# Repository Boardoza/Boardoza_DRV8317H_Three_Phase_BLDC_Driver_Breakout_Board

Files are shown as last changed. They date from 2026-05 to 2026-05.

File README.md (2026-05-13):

# Boardoza DRV8317H Three-Phase BLDC Motor Driver Breakout Board

The **Boardoza DRV8317H Breakout Board** is a high-performance, integrated **three-phase BLDC motor driver** designed for compact and efficient motor control applications. Based on the **Texas Instruments DRV8317H**, this device integrates three half-bridges with low R<sub>DS(ON)</sub> MOSFETs, programmable current sensing, and advanced protection mechanisms into a single solution.

Supporting supply voltages up to **24V (absolute maximum)** and delivering up to **5A peak output current**, the DRV8317H is ideal for robotics, steward and gimbal systems, drones, industrial automation, pumps, and smart motorized systems. With flexible control options such as **6x PWM mode and 3x PWM mode**, this board allows both simple and advanced motor control implementations.

## [Click here to purchase!](https://www.ozdisan.com/ureticiler/boardoza)

| Front Side | Back Side |
|:---:|:---:|
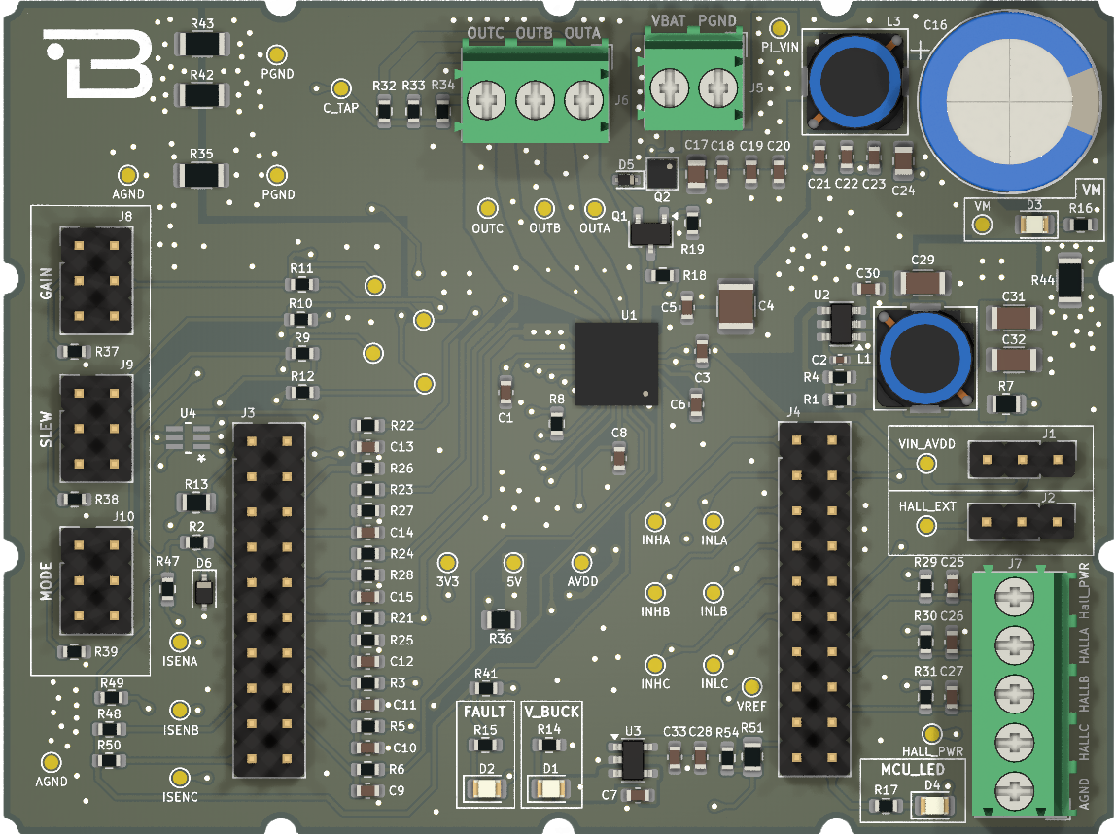
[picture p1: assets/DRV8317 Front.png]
DRV8317H Front
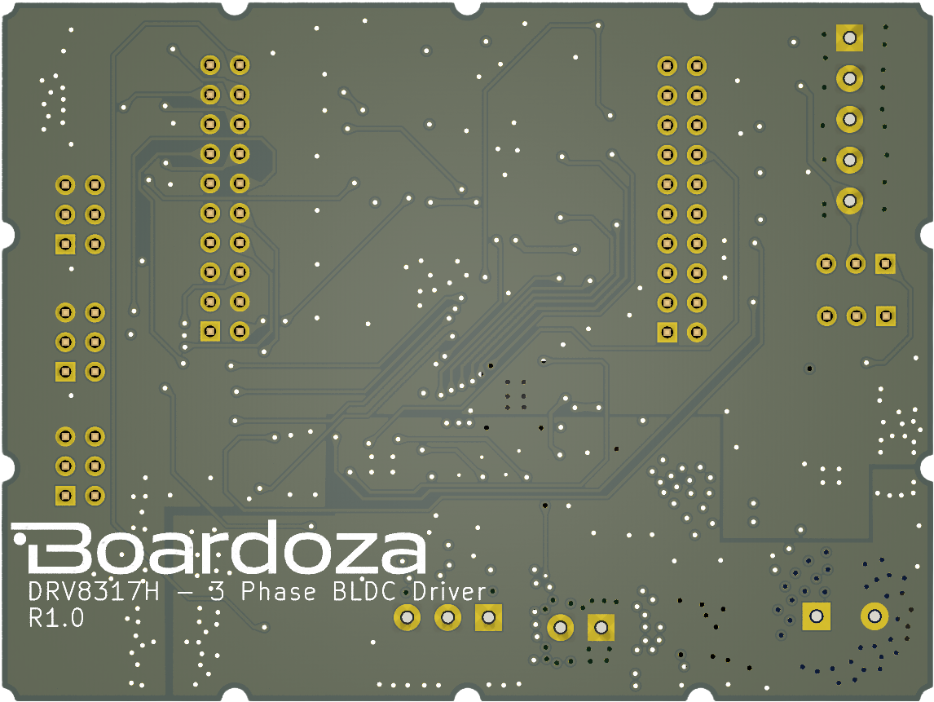
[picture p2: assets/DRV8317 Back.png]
DRV8317H Back
|  |  |

---

## Key Features

- **Integrated Three-Phase Driver:** Drives BLDC and PMSM motors with a compact all-in-one solution.
- **Up to 5A Peak Output Current:** Suitable for medium-power motor applications.
- **Flexible Control Options:** Supports **6x PWM** and **3x PWM**.
- **High PWM Frequency Support:** Operates with PWM frequencies up to **200 kHz**.
- **Integrated Current Sensing:** No external shunt resistor required.
- **Programmable Slew Rate:** Helps reduce EMI and optimize switching performance.
- **Comprehensive Protection Features:** Includes UVLO, OVP, CPUV, OCP, OTW, and OTS protections.
- **Shoot-Through Protection:** Integrated hardware-level safety for reliable operation.

---

## Technical Specifications

**Model:** DRV8317H  
**Manufacturer:** Boardoza  
**Manufacturer IC:** Texas Instruments  
**Driver Type:** Integrated 3-Phase Gate Driver with MOSFETs  
**Functions:** Three-Phase PWM BLDC Motor Driver  
**Input Voltage (VM):** 4.5V – 20V (24V Absolute Maximum)  
**Peak Output Current:** 5A (per phase, peak)  
**Control Interfaces:** 6x PWM / 3x PWM    
**Maximum PWM Frequency:** 200 kHz  
**RDS(ON) (HS + LS):** 130 mΩ (typical at 25°C)  
**Current Sensing:** Integrated (Programmable Gain)  
**Protection Features:**  
- UVLO (Undervoltage Lockout)  
- OVP (Overvoltage Protection)  
- CPUV (Charge Pump Undervoltage)  
- OCP (Overcurrent Protection)  
- OTW (Overtemperature Warning)  
- OTS (Overtemperature Shutdown)  

**Operating Temperature:** -40°C to +125°C  
**Board Dimensions:** 60mm x 80mm  

---

## Board Pinout / User Guide

>Pin functions are multiplexed and may vary depending on selected control mode (6x PWM, 3x PWM).  
For detailed pin descriptions, alternate-function mappings, electrical characteristics, and application examples, please refer to the official Board User Guide:
[DRV8317H User Guide.pdf](./assets/DRV8317H%20User%20Guide.pdf)

---

## Board Dimensions

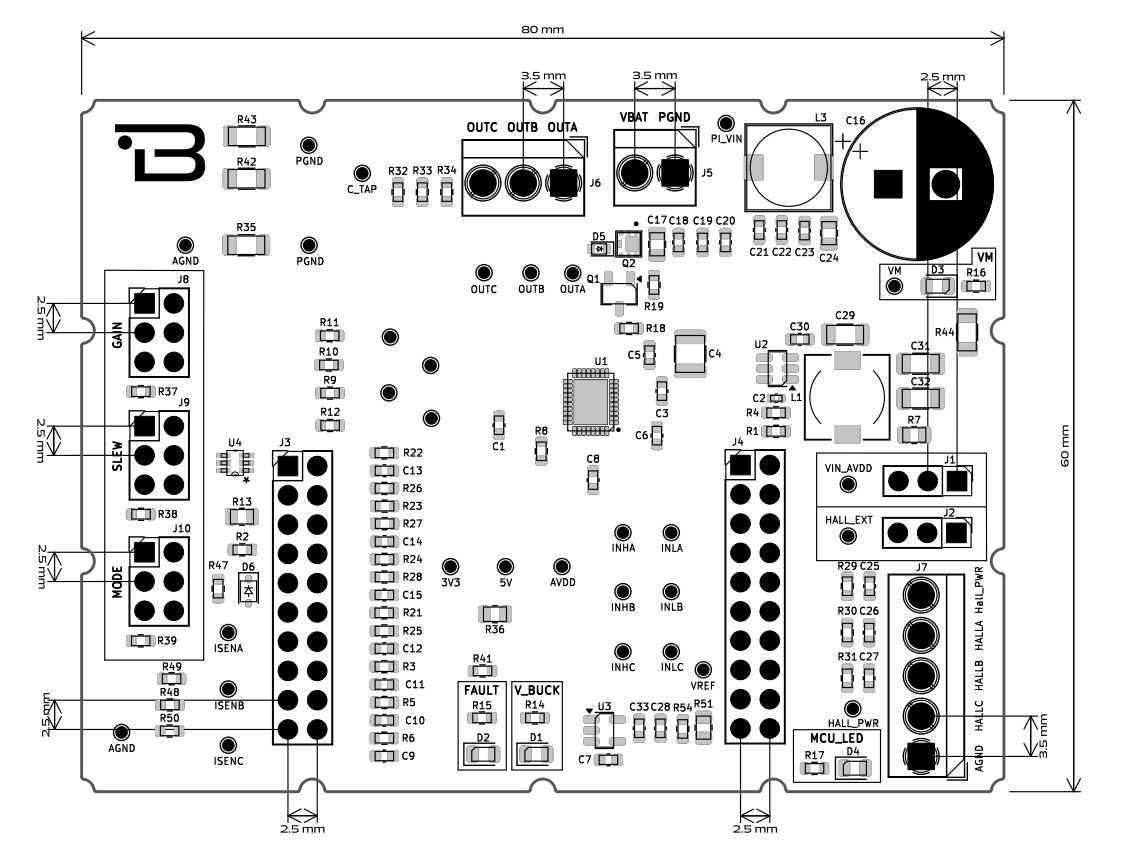
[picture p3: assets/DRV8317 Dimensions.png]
DRV8317H Board Dimensions


---

## Step Files

[Boardoza DRV8317H.step](./assets/DRV8317%20Step.step)

---

## Datasheet

[DRV8317H Datasheet.pdf](./assets/DRV8317%20Datasheet.pdf)

---

## Version History

- v1.0.0 - Initial Release

---

## Support

- If you have any questions or need support, please contact **support@boardoza.com**

---

## **License**

This repository contains both hardware and software components:

### **Hardware Design**

[][cc-by-sa]

All hardware design files are licensed under [Creative Commons Attribution-ShareAlike 4.0 International License][cc-by-sa].

[cc-by-sa]: http://creativecommons.org/licenses/by-sa/4.0/
[cc-by-sa-shield]: https://img.shields.io/badge/License-CC%20BY--SA%204.0-lightgrey.svg

### **Software/Firmware**

[][bsd]

All software and firmware are licensed under [BSD 3-Clause License][bsd].

[bsd]: https://opensource.org/licenses/BSD-3-Clause
[bsd-shield]: https://img.shields.io/badge/License-BSD%203--Clause-blue.svg

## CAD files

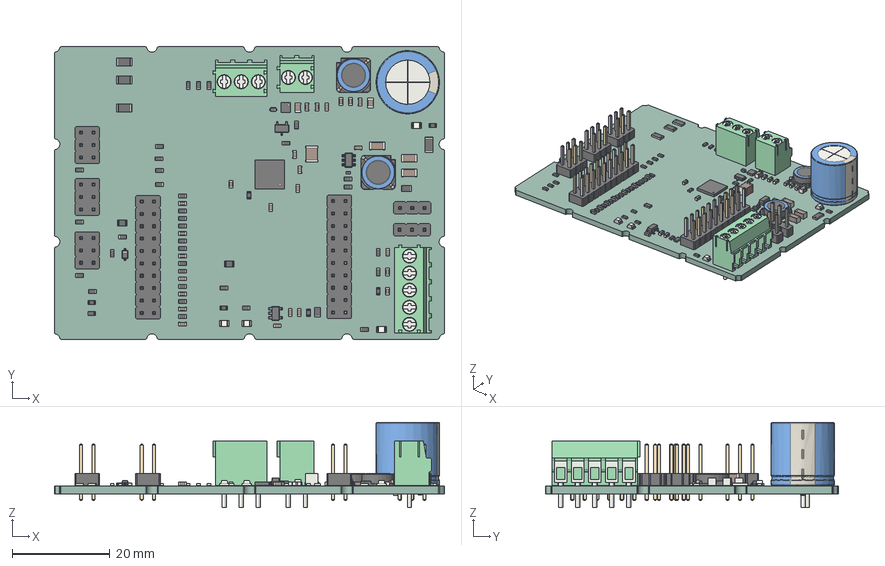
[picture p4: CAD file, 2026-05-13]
assets/DRV8317 Step.step
80.0 x 60.0 x 17.5 mm
R_0603_1608Metric x 40
D_SOD_523
C_0603_1608Metric x 25
C_0805_2012Metric x 2
TSOT_23
D_SOD_323
PinHeader_1x03_P254mm_Vertical x 2
R_0805_2012Metric x 4
SOT_23_5
Sf㱟fd_sp x 2
C_1206_3216Metric x 3
LED_0805_2012Metric x 4
PinHeader_2x10_P254mm_Vertical x 2
PinHeader_2x03_P254mm_Vertical x 3
C_1210_3225Metric
TerminalBlock_Phoenix_PT_15_2_35_H_1x02_P350mm_Horizontal
TerminalBlock_Phoenix_PT_15_3_35_H_1x03_P350mm_Horizontal
TerminalBlock_Phoenix_PT_15_5_35_H_1x05_P350mm_Horizontal
DFN-6-1EP_2x2mm_Pitch0.65mm
R_1206_3216Metric x 4
Texas_RHH0036C_VQFN-36-1EP_6x6mm_P0.5mm_EP4.4x4.4mm
C_0402_1005Metric
CP_Radial_D130mm_P500mm
SOT_23_6
_autosave-B-DRV8317-BRK_PCB

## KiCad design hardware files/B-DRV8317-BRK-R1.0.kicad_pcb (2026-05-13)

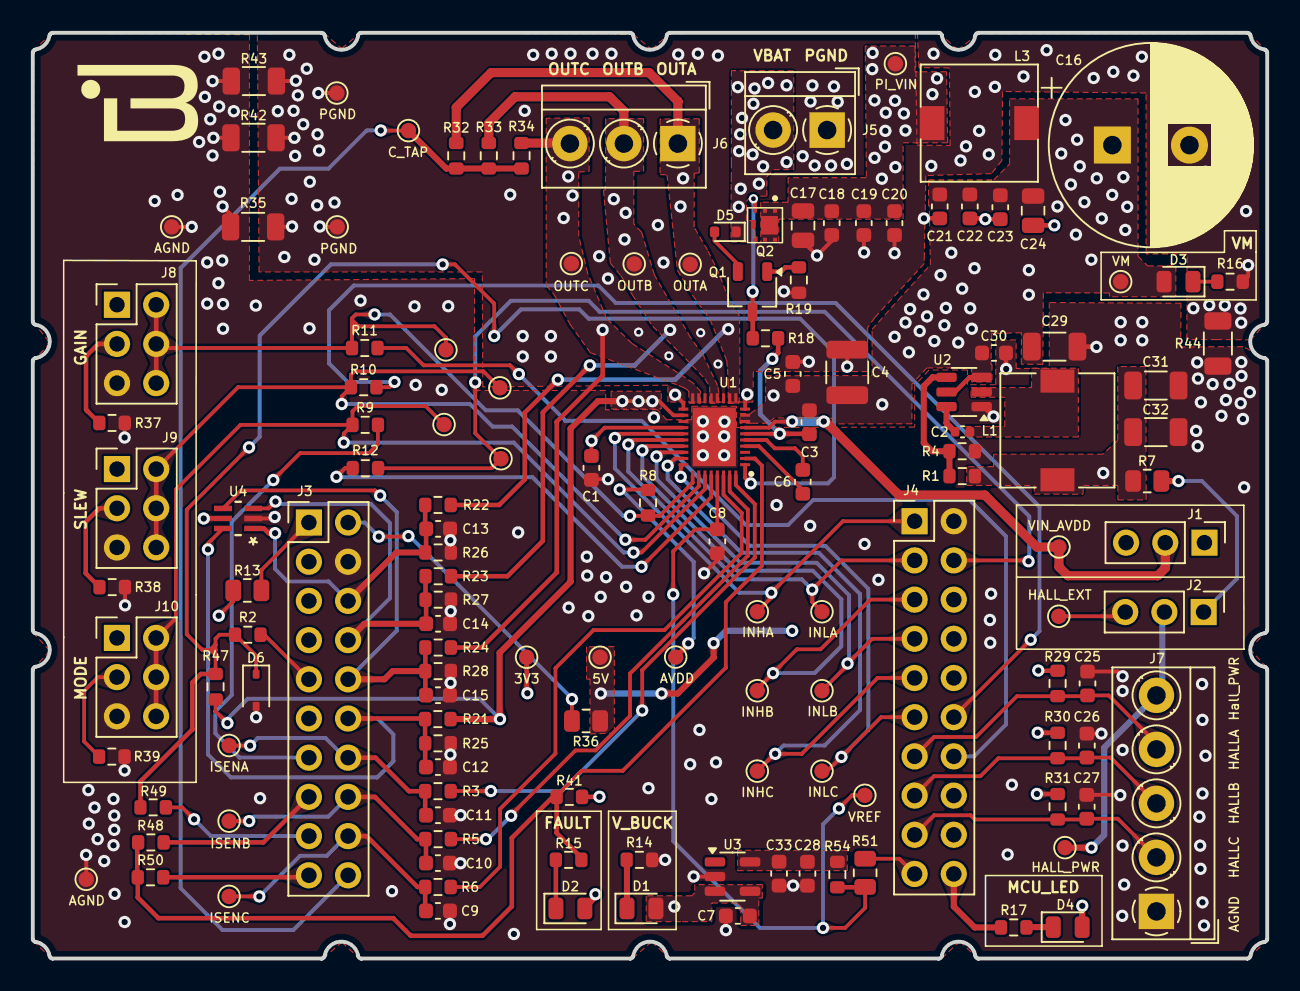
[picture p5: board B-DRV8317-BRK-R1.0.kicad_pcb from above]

Board: 4 copper layers, 80.0 x 60.0 mm, 135 parts (0 on the bottom side), 71 nets.

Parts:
C1: 4.7uF; C_0603_1608Metric
C2: 0,1uF; C_0402_1005Metric
C3, C28: 1uF; C_0603_1608Metric
C4: 10uF; C_1210_3225Metric
C5, C6, C7, C8, C12, C13, C14, C15, C18, C23, C30, C33: 100nF; C_0603_1608Metric
C9, C10, C11: 22pF; C_0603_1608Metric
C16: 330uF; CP_Radial_D13.0mm_P5.00mm
C17, C24: 1uF; C_0805_2012Metric
C19, C22: 10nF; C_0603_1608Metric
C20, C21, C25, C26, C27: 1nF; C_0603_1608Metric
C29: 2,2uF; C_1206_3216Metric
C31, C32: 22uF; C_1206_3216Metric
D1, D3: GREEN; LED_0805_2012Metric
D2: YELLOW; LED_0805_2012Metric
D4: ORANGE; LED_0805_2012Metric
D5: CDSU101A; D_SOD-523
D6: SZMM3Z3V3ST1G; D_SOD-323
J1, J2: Conn_01x03; PinHeader_1x03_P2.54mm_Vertical
J3, J4: Conn_02x10_Odd_Even; PinHeader_2x10_P2.54mm_Vertical
J5: Conn_01x02; TerminalBlock_MetzConnect_Type059_RT06302HBWC_1x02_P3.50mm_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
J6: Conn_01x03; TerminalBlock_MetzConnect_Type059_RT06303HBWC_1x03_P3.50mm_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
J7: Conn_01x05; TerminalBlock_MetzConnect_Type059_RT06305HBWC_1x05_P3.50mm_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
J8, J9, J10: Conn_02x03_Odd_Even; PinHeader_2x03_P2.54mm_Vertical
L1: SRI0704-100M; L_7.3x7.3_H4.5
L3: 1uH; L_Wuerth_WE-PD-Typ-7345
Q1: FMMT620TA; TSOT-23
Q2: BUK9D23-40EX; TRANS_BUK9D23-40EX
R1, R32, R33, R34: 100k; R_0603_1608Metric
R2, R9, R10, R11, R12, R48, R49, R50, R54: 0; R_0603_1608Metric
R3, R5, R6, R14, R15, R17: 330R; R_0603_1608Metric
R4: 22.1k; R_0603_1608Metric
R7, R13, R36, R51: 0; R_0805_2012Metric
R8, R41: 5.1k; R_0603_1608Metric
R16: 4.70k; R_0603_1608Metric
R18, R19, R29, R30, R31, R47: 10k; R_0603_1608Metric
R21, R22, R23, R24: 42.2k; R_0603_1608Metric
R25, R26, R27, R28: 6.04k; R_0603_1608Metric
R35, R42, R43, R44: 0; R_1206_3216Metric
R37, R38, R39: 47k; R_0603_1608Metric
TP1: OUTA; TestPoint_Pad_D1.0mm
TP2: OUTB; TestPoint_Pad_D1.0mm
TP3: OUTC; TestPoint_Pad_D1.0mm
TP4: VIN_AVDD; TestPoint_Pad_D1.0mm
TP5: PI_VIN; TestPoint_Pad_D1.0mm
TP6: VREF; TestPoint_Pad_D1.0mm
TP7: ISENC; TestPoint_Pad_D1.0mm
TP8: ISENB; TestPoint_Pad_D1.0mm
TP9: ISENA; TestPoint_Pad_D1.0mm
TP10: VM; TestPoint_Pad_D1.0mm
TP11, TP16: GNDA; TestPoint_Pad_D1.0mm
TP12, TP17: GNDP; TestPoint_Pad_D1.0mm
TP14: HALL_EXT; TestPoint_Pad_D1.0mm
TP15: C_TAP; TestPoint_Pad_D1.0mm
TP18: AVDD; TestPoint_Pad_D1.0mm
TP19: 3V3; TestPoint_Pad_D1.0mm
TP20: INHA; TestPoint_Pad_D1.0mm
TP21: INLA; TestPoint_Pad_D1.0mm
TP22: SCLK; TestPoint_Pad_D1.0mm
TP23: INHB; TestPoint_Pad_D1.0mm
TP24: SDI; TestPoint_Pad_D1.0mm
TP25: INLB; TestPoint_Pad_D1.0mm
TP26: SDO; TestPoint_Pad_D1.0mm
TP27: INHC; TestPoint_Pad_D1.0mm
TP28: nSCS; TestPoint_Pad_D1.0mm
TP29: INLC; TestPoint_Pad_D1.0mm
TP30: +5V; TestPoint_Pad_D1.0mm
TP31: HALL_PWR; TestPoint_Pad_D1.0mm
U1: DRV8317HREER; QFN40P400X500X80-37N-D
U2: LMR51420YFDDCR; SOT-23-6
U3: REF4132B33DBVRQ1; SOT-23-5
U4: TPD4S009DCKR; DCK6

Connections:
3.3_BK: C31.1, C32.1, L1.2, R1.2, R7.2
3V3: C7.2, D1.2 (A), D2.2 (A), D4.2 (A), J2.1, R7.1, R13.1, TP19.1, U3.3 (EN), U3.4 (VIN)
+5V: J1.1, R36.2, TP30.1
/CSAREF: C8.2, R51.1, R54.1, TP6.1, U1.33 (CSAREF)
/C_TAP: J3.20, R32.1, R33.1, R34.1, TP15.1
/HALLA: C25.1, J4.13, J7.4, R29.1
/HALLB: C26.1, J4.15, J7.3, R30.1
/HALLC: C27.1, J4.17, J7.2, R31.1
/INHA: J4.1, TP20.1, U1.23 (INHA)
/INHB: J4.5, TP23.1, U1.25 (INHB)
/INHC: J4.9, TP27.1, U1.27 (INHC)
/INLA: J4.3, TP21.1, U1.24 (INLA)
/INLB: J4.7, TP25.1, U1.26 (INLB)
/INLC: J4.11, TP29.1, U1.28 (INLC)
/ISENA: C11.2, J3.14, R3.2, TP9.1
/ISENB: C10.2, J3.16, R5.2, TP8.1
/ISENC: C9.2, J3.18, R6.2, TP7.1
/MCU_LED: J4.20, R17.1
/OUTA: J6.1, R22.2, R32.2, TP1.1, U1.11 (OUTA_1), U1.12 (OUTA_2)
/OUTB: J6.2, R23.2, R33.2, TP2.1, U1.14 (OUTB_1), U1.15 (OUTB_2)
/OUTC: J6.3, R24.2, R34.2, TP3.1, U1.17 (OUTC_1), U1.18 (OUTC_2)
/SCLK: J3.13, R9.1
/SCLK/MODE: J10.2, J10.4, J10.6, R9.2, TP22.1, U1.31 (SCLK)
/SDI: J4.12, R10.1
/SDI/SLEW: J9.2, J9.4, J9.6, R10.2, TP24.1, U1.30 (SDI)
/SDO: J4.14, R11.1
/SDO/GAIN: J8.2, J8.4, J8.6, R8.1, R11.2, TP26.1, U1.29 (SDO)
/SOA: R3.1, U1.36 (SOA)
/SOB: R5.1, U1.35 (SOB)
/SOC: R6.1, U1.34 (SOC)
/VSENA: C13.1, J3.6, R22.1, R26.2, U4.1 (D1+)
/VSENB: C14.1, J3.8, R23.1, R27.2, U4.3 (D2+)
/VSENC: C15.1, J3.10, R24.1, R28.2, U4.4 (D2-)
/VSENVM: C12.1, J3.12, R21.1, R25.2, U4.6 (D1-)
/nFAULT: R15.1, R41.1, R48.1, R50.1, U1.2 (NFAULT)
/nSCS: J4.4, R12.1, TP28.1
/nSCS/NC: R12.2, U1.32 (nSCS)
AGND: C1.2, C7.1, C8.1, C9.1, C10.1, C11.1, C12.2, C13.2, C14.2, C15.2, C25.2, C26.2, C27.2, C28.1, C29.1, C30.1, C31.2, C32.2, C33.1, D6.2 (A), J3.4, J4.2, J7.1, J8.5, J9.5, J10.5, R4.1, R14.1, R25.1, R26.1, R27.1, R28.1, R35.2, R37.1, R38.1, R39.1, R42.2, R43.2, R44.2, TP11.1, TP16.1, U1.21 (AGND), U1.37 (GND), U2.1 (GND), U3.2 (GND), U4.2 (GND)
AVDD: C1.1, J8.1, J9.1, J10.1, R8.2, R29.2, R30.2, R31.2, R41.2, TP18.1, U1.22 (AVDD), U4.5 (VCC)
HALL_PWR: J2.2, J7.5, TP31.1
unnamed: C17.1, C18.1, C19.1, C20.1, L3.1, Q2.1, Q2.2, Q2.5, Q2.6, Q2.7, TP5.1
unnamed: D1.1 (K), R14.2
unnamed: D2.1 (K), R15.2
unnamed: D3.1 (K), R16.2
unnamed: D4.1 (K), R17.2
unnamed: D5.2 (A), Q1.2 (E)
unnamed: J2.3, TP14.1
unnamed: J3.1, R13.2
unnamed: J3.2, R36.1
unnamed: J3.9, R2.2
unnamed: J3.15, R48.2
unnamed: J3.17, R49.2
unnamed: J3.19, R50.2
unnamed: J4.19, R51.2
unnamed: J8.3, R37.2
unnamed: J9.3, R38.2
unnamed: J10.3, R39.2
unnamed: Q1.1 (B), R19.2
unnamed: Q1.3 (C), Q2.3, R18.2
unnamed: C6.2, U1.5 (CPH)
unnamed: C6.1, U1.4 (CPL)
unnamed: C2.2, U2.6 (CB)
unnamed: R1.1, R4.2, U2.4 (FB)
unnamed: C2.1, L1.1, U2.2 (SW)
unnamed: C28.2, C33.2, R54.2, U3.5 (VREF)
PGND: C4.2, C5.2, C16.2, C17.2, C18.2, C19.2, C20.2, C21.2, C22.2, C23.2, C24.2, J5.1, R16.1, R19.1, R35.1, R42.1, R43.1, R44.1, TP12.1, TP17.1, U1.10 (PGND_1), U1.13 (PGND_2), U1.16 (PGND_3), U1.19 (PGND_4)
VBAT: D5.1 (K), J5.2, Q2.4, Q2.8
VCP: C3.2, R18.1, U1.6 (CP)
VIN_AVDD: J1.2, TP4.1, U1.7 (VIN_AVDD)
VM: C3.1, C4.1, C5.1, C16.1, C21.1, C22.1, C23.1, C24.1, C29.2, C30.2, D3.2 (A), J1.3, L3.2, R21.2, R47.2, TP10.1, U1.8 (VM_1), U1.9 (VM_2), U1.20 (VM_3), U2.3 (VIN), U2.5 (EN)
nSLEEP: D6.1 (K), R2.1, R47.1, R49.1, U1.1 (~SLEEP)

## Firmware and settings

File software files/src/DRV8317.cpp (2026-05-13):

#include "DRV8317.h"
uint8_t constant = pow(1, 1/3);

/**
 * @brief Constructor for the DRV8317 class.
 * @param in1LPin Pin number for in1L.
 * @param in2LPin Pin number for in2L.
 * @param in3LPin Pin number for in3L.
 * @param pwmPinA PWM pin A number.
 * @param pwmPinB PWM pin B number.
 * @param pwmPinC PWM pin C number.
 * @param nSleepPin nSleep pin number.
 * @param hallA Hall sensor A pin number.
 * @param hallB Hall sensor B pin number.
 * @param hallC Hall sensor C pin number.
 */
DRV8317::DRV8317(uint8_t in1LPin, uint8_t in2LPin, uint8_t in3LPin, uint8_t pwmPinA, uint8_t pwmPinB, uint8_t pwmPinC, uint8_t nSleepPin, uint8_t hallA, uint8_t hallB, uint8_t hallC) {
    _in1LPin = in1LPin;
    _in2LPin = in2LPin;
    _in3LPin = in3LPin;
    _pwmPinA = pwmPinA;
    _pwmPinB = pwmPinB;
    _pwmPinC = pwmPinC;
    _hallA = hallA;
    _hallB = hallB;
    _hallC = hallC;
    _nSleepPin = nSleepPin;
    _direction = true; // Default direction: clockwise
    _speed = 128;      // Default speed: medium
}

/**
 * @brief Initializes the DRV8317 motor driver.
 * 
 * This function configures the necessary pins and settings to start using the DRV8317 motor driver.
 * It sets the pin modes for motor control, PWM outputs, sleep pin, and hall sensors.
 * It also sets the PWM frequency to 100kHz, enables the motor driver, and prepares it for operation.
 * 
 * @note Before calling this function, make sure to set the required parameters using the constructor.
 */
void DRV8317::begin() {
    pinMode(_in1LPin, OUTPUT);
    pinMode(_in2LPin, OUTPUT);
    pinMode(_in3LPin, OUTPUT);
    pinMode(_pwmPinA, OUTPUT);
    pinMode(_pwmPinB, OUTPUT);
    pinMode(_pwmPinC, OUTPUT);
    pinMode(_nSleepPin, OUTPUT);
    pinMode(_hallA, INPUT);
    pinMode(_hallB, INPUT);
    pinMode(_hallC, INPUT);
    analogWriteFrequency(100000);
    enable();
    //disable();
}

/**
 * @brief Sets the PWM value for PWM pin A.
 * @param pwmValue The PWM value to set for PWM pin A.
 */
void DRV8317::setPWMA(uint8_t pwmValue) {
    analogWrite(_pwmPinA, pwmValue);
}

/**
 * @brief Sets the PWM value for PWM pin B.
 * @param pwmValue The PWM value to set for PWM pin B.
 */
void DRV8317::setPWMB(uint8_t pwmValue) {
    analogWrite(_pwmPinB, pwmValue);
}

/**
 * @brief Sets the PWM value for PWM pin C.
 * @param pwmValue The PWM value to set for PWM pin C.
 */
void DRV8317::setPWMC(uint8_t pwmValue) {
    analogWrite(_pwmPinC, pwmValue);
}

/**
 * @brief Sets the PWM values for all PWM pins.
 * @param pwmA The PWM value for PWM pin A.
 * @param pwmB The PWM value for PWM pin B.
 * @param pwmC The PWM value for PWM pin C.
 */
void DRV8317::setPWMAll(uint8_t pwmA, uint8_t pwmB, uint8_t pwmC) {
    analogWrite(_pwmPinA, pwmA);
    analogWrite(_pwmPinB, pwmB);
    analogWrite(_pwmPinC, pwmC);
}

/**
 * @brief Sets the PWM values for all low-side PWM pins.
 * @param pwmA The PWM value for in1LPin.
 * @param pwmB The PWM value for in2LPin.
 * @param pwmC The PWM value for in3LPin.
 */
void DRV8317::setPWMLowSide(uint8_t pwmA, uint8_t pwmB, uint8_t pwmC) {
    analogWrite(_in1LPin, pwmA);
    analogWrite(_in2LPin, pwmB);
    analogWrite(_in3LPin, pwmC);
}

/**
 * @brief Enables all low-side drivers.
 * 
 * This function sets the low-side driver pins (_in1LPin, _in2LPin, _in3LPin) to HIGH,
 * enabling the low-side drivers for the DRV8317 motor driver.
 */
void DRV8317::enableLowside() {
    digitalWrite(_in1LPin, HIGH);
    digitalWrite(_in2LPin, HIGH);
    digitalWrite(_in3LPin, HIGH);
}

/**
 * @brief Disables all low-side drivers.
 * 
 * This function sets the low-side driver pins (_in1LPin, _in2LPin, _in3LPin) to LOW,
 * disabling the low-side drivers for the DRV8317 motor driver.
 */
void DRV8317::disabLowside() {
    digitalWrite(_in1LPin, LOW);
    digitalWrite(_in2LPin, LOW);
    digitalWrite(_in3LPin, LOW);
}

/**
 * @brief Enables the DRV8317 motor driver.
 * 
 * This function sets the nSleepPin to HIGH, enabling the DRV8317 motor driver for operation.
 */
void DRV8317::enable() {
    digitalWrite(_nSleepPin, HIGH);
}

/**
 * @brief Disables the DRV8317 motor driver.
 * 
 * This function sets the nSleepPin to LOW, disabling the DRV8317 motor driver.
 */
void DRV8317::disable() {
    digitalWrite(_nSleepPin, LOW);
}

/**
 * @brief Sets the direction of the motor rotation.
 * 
 * This function sets the direction of the motor rotation based on the specified direction value.
 * 
 * @param direction The direction value to set (0 or 1).
 */
void DRV8317::setDirection(uint8_t direction) {
    _direction = direction;
}

/**
 * @brief Sets the speed of the motor.
 * 
 * This function sets the speed of the motor based on the specified speed value and applies the corresponding phase configuration.
 * 
 * @param speed The speed value to set (0-255).
 */
void DRV8317::setSpeed(uint8_t speed) {
    _speed = speed;
    applyPhase();
}

/**
 * @brief Applies the braking mechanism to stop the motor.
 * 
 * This function applies a braking mechanism to stop the motor by setting the appropriate pins and disabling the motor driver.
 */
void DRV8317::brake() {
    digitalWrite(_in1LPin, LOW);
    digitalWrite(_in2LPin, LOW);
    digitalWrite(_in3LPin, LOW);
    disable();
}

/**
 * @brief Allows the motor to coast to a stop.
 * 
 * This function releases the motor to coast to a stop by setting the output pins LOW and optionally stopping PWM signals.
 */
void DRV8317::coast() {
    // Make the output pins LOW to release the motor
    digitalWrite(_in1LPin, LOW);
    digitalWrite(_in2LPin, LOW);
    digitalWrite(_in3LPin, LOW);

    // Stop PWM signals (optional)
    analogWrite(_pwmPinA, 0);
    analogWrite(_pwmPinB, 0);
    analogWrite(_pwmPinC, 0);
}

/**
 * @brief Initiates an emergency stop of the motor.
 * 
 * This function performs an emergency stop of the motor by applying the brake mechanism and additional security measures if required.
 */
void DRV8317::emergencyStop() {
    brake();
    // Additional security measures can be added
}

/**
 * @brief Applies the phase configuration based on the speed and direction settings.
 * 
 * This function calculates the PWM value based on the speed setting and direction, and sets the PWM signals accordingly.
 */
void DRV8317::applyPhase() {
    uint8_t pwmValue = map(_speed, 0, 255, 0, 255);
    if(_direction) {
        setPWMAll(pwmValue, pwmValue, pwmValue);
    } else {
        setPWMAll(255 - pwmValue, 255 - pwmValue, 255 - pwmValue);
    }
}
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

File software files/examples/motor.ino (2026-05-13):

#include "DRV8317.h"

DRV8317 motordriver(0, 1, 2, 3, 4, 5, 6, 7, 8, 9);
uint8_t toggle = 0;
uint16_t count = 0;

void setup() {
  Serial.begin(115200);
  while(!Serial) {

  }

motordriver.begin();

motordriver.setDirection(1);
}

uint16_t count_=1;
uint16_t speed=0;
uint16_t CW=1;
uint16_t direction=1;

void loop() {

/*if(count < 1000) {
  count++;
} else {
  count = 0;
  if(toggle) {
    toggle = 0;
  } else {
    toggle = 1;
  }
}*/


count_=count_+1;
if (count_>50)
  {
  count_=0;
  if (CW)
    {
    if (speed<255)
      {  
      speed=speed+1;
      }
    else
      {
      CW=0;  
      }
    }
  else
    {
    if (speed>0)
      {
      speed=speed-1;  
      }
    else
      {
      CW=1;
      if (direction)
        direction=0;
      else
        direction=1;  
      }    
    }    
  }

//motordriver.turnMotorWithHall(0);
//motordriver.turnMotorPWMWithHall(direction,speed);
motordriver.turnMotorSinWithHall(0,1);
}

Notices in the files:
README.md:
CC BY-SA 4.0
